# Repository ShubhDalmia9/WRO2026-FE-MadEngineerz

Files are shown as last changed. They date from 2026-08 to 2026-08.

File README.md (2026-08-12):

# 🏁 WRO 2026 Future Engineers — MadEngineerz

<div align="center">

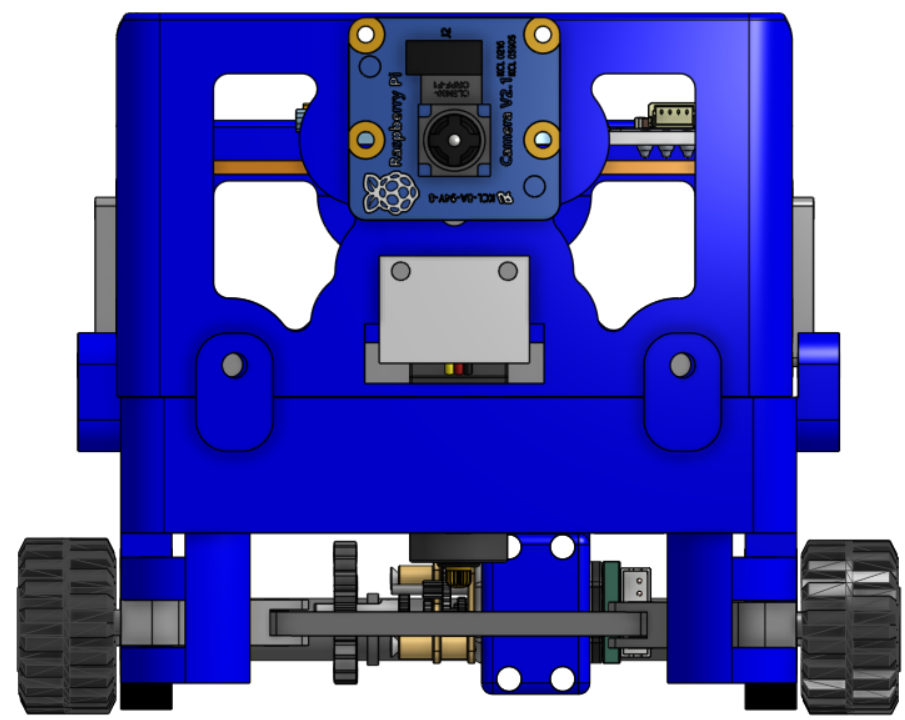
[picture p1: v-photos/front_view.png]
MadEngineerz autonomous vehicle


**Small. Efficient. Simple.**

</div>

---

Welcome to the repository of **Team MadEngineerz**, competing in the **World Robot Olympiad™ Future Engineers 2026** category.

We set out to build a compact autonomous vehicle in which every part earns its place. The design philosophy is stated in three words in our own ideology document, and it is not decoration: it decided the chassis dimensions, the drivetrain, the electronics construction method and the software architecture. Where a simpler answer was sufficient, we took it. Where minimalism would have cost capability, we did not.

The vehicle measures **121 mm (L) × 83 mm (W) × 83 mm (H)**. The printed mechanical structure, with no electronics fitted, weighs **72.92 g**. That figure is the sum of every printed part in the build and not an estimate; the breakdown is published part by part in the [Models documentation](models/README.md).

Every mechanical component was designed by the team in Onshape and manufactured in-house. Every electrical connection was made by the team on perfboard. Every line of software was written by the team. This repository contains all of it, along with the research documents behind each decision.

---

## 📚 Table of Contents

- [📂 Complete Documentation Structure](#complete-documentation-structure)
- [👥 The Team](#the-team)
- [🎯 Challenge Overview](#challenge-overview)
- [🤖 Our Robot](#our-robot)
- [🧭 Engineering Philosophy](#engineering-philosophy)
- [⚙️ Mechanical Systems](#mechanical-systems)
- [🔧 Electronic Systems](#electronic-systems)
- [💻 Software Architecture](#software-architecture)
- [🔬 Research & Development](#research--development)
- [🧪 Testing & Iteration](#testing--iteration)
- [🛠️ Engineering Challenges](#engineering-challenges)
- [🚗 Vehicle Photos](#vehicle-photos)
- [🌐 GitHub Utilization](#github-utilization)
- [♻️ Replication](#replication)

---

## 📂 Complete Documentation Structure 

<div align="center">

### Each folder carries its own detailed technical README

| 📁 Folder | 🎯 Technical Content | 📖 Documentation |
|---|---|---|
| **⚙️ Models** | **Mechanical engineering**<br>• Onshape CAD and 3MF manufacturing files<br>• Chassis, steering and drivetrain design<br>• Transmission and speed analysis<br>• Design iteration record | [🔗 Models Documentation](models/README.md) |
| **🔌 Schemes** | **Electrical engineering**<br>• Complete wiring schematic<br>• Power distribution and consumption analysis<br>• Component pinouts and reference schematics<br>• Full bill of materials and datasheets | [🔗 Schemes Documentation](schemes/README.md) |
| **💻 Source** | **Software**<br>• Raspberry Pi vision and navigation<br>• Arduino Nano actuator control<br>• Serial protocol and failsafe<br>• Eight research documents | [🔗 Software Documentation](src/README.md) |
| **📚 Other** | **Research and references**<br>• Design ideology<br>• Steering and propulsion research<br>• Battery placement study<br>• Component reference images | [🔗 Other Resources](other/README.md) |
| **👥 Team Photos** | Official and informal team photographs | [🔗 Team Photos](t-photos/README.md) |
| **🚗 Vehicle Photos** | Six orthographic views with component identification | [🔗 Vehicle Photos](v-photos/README.md) |

</div>

---

## 👥 The Team 

MadEngineerz is a student robotics team competing in WRO 2026 Future Engineers. Between two members the project covers mechanical design and CAD, electronics, software, strategy and research, which is why the documentation in this repository spans all of those disciplines rather than one.

<div align="center">

| Member | Grade | Role |
|---|:---:|---|
| **Shubh Dalmia** — *Team Leader* | 10 | Electronics, Mechanical Design, CAD, Strategy, Research |
| **Daksh Gupta** | 9 | Electronics, Strategy Integration, Software, Research |

**Coach:** Vipin Kumar

</div>

<div align="center">
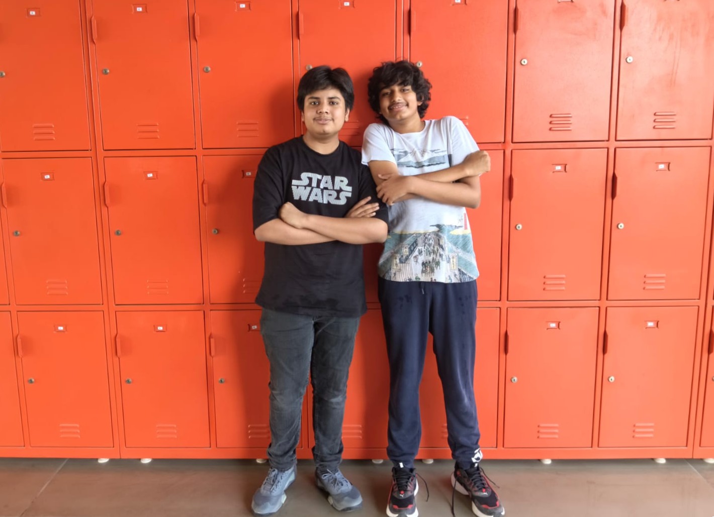
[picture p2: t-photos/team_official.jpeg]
MadEngineerz official team photo

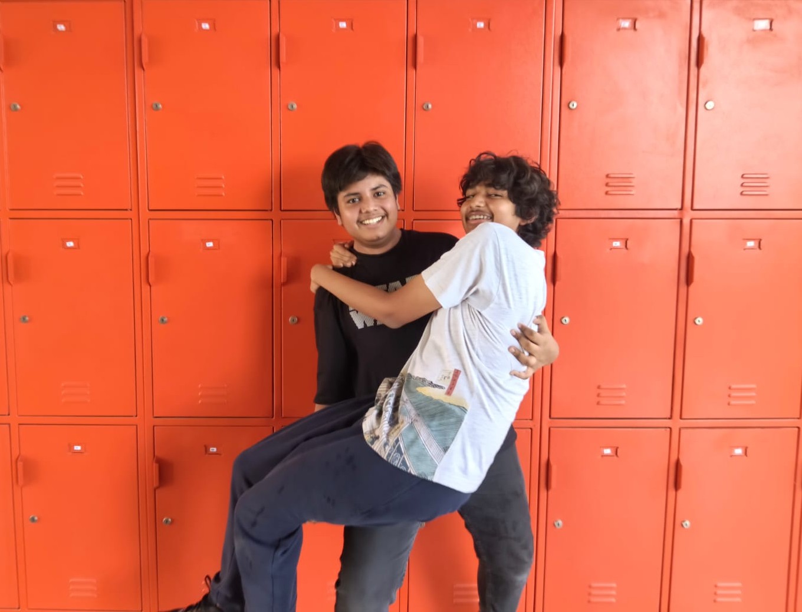
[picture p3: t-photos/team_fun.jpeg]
MadEngineerz informal team photo

</div>
<p align="center">
  <em>Official and informal team photographs. Full documentation in <a href="t-photos/README.md">t-photos</a>.</em>
</p>

---

## 🎯 Challenge Overview 

WRO Future Engineers sets two autonomous navigation problems on the same field. Our approach to each is summarised below and documented in full in the [Software Documentation](src/README.md).

### 🚀 Open Challenge

The vehicle navigates the track without obstacles, using the walls themselves as the reference.

```
Lane centering between the two walls, biased toward the inner wall
                              |
                              v
                Corner line detection (camera)
                              |
                              v
                    Corner line counting
                              |
                              v
                      11 lines counted
                              |
                              v
          Camera navigation yields to encoder odometry
                              |
                              v
        Drive a pre-calculated distance, then full stop
```

The control algorithm holds the vehicle centred between the inner and outer walls, with a deliberate bias toward the inner boundary to optimise cornering radii. Lap progress is tracked by counting corner marker lines through the camera. After the eleventh line the system changes state entirely: vision hands over to encoder odometry, which drives a known distance and stops.

### 🚧 Obstacle Challenge

The vehicle must pass red and green pillars on the correct side.

| Stage | Method |
|---|---|
| **Detection** | Raw YUV422 capture, U and V chrominance masking, red and green objects |
| **Centre calculation** | Mean X and Y of all masked pixels gives the pillar centroid |
| **Angle reference** | The camera is fixed on the chassis centreline, so the frame centre is 0° |
| **Relative angle** | Pixel offset between the pillar centroid and the frame centreline |
| **Avoidance** | Colour determines which side; angle determines how hard |
| **Steering** | PID control of the steering servo |

The target avoidance angle decreases approximately linearly as the pillar's pixel footprint grows, which indicates closing distance. The result is a smooth sweeping curve around a pillar rather than a late swerve.

### 📐 Where the mechanical engineering evidence sits

The mechanical evaluation looks at chassis design choices, the steering and drive mechanism, torque and speed reasoning, stability and rigidity, and the justification behind each decision. This table points to where each is evidenced rather than asserted.

| Evaluation area | Where it is documented |
|---|---|
| **Chassis design choices** | [Two-part chassis](#mechanical-systems) here, full reasoning and load-path analysis in [Models](models/README.md) |
| **Steering mechanism** | [Ackermann steering](#mechanical-systems), including why the short wheelbase makes the geometry matter more |
| **Drive mechanism** | [Rear-wheel drive and spur gear transmission](#mechanical-systems), including why the drive path is a straight shaft |
| **Torque and speed reasoning** | The 4:3 step-up derivation below, with the torque trade-off and why it suits this mass |
| **Stability and rigidity** | Closed-box architecture, 3 mm walls, eight-screw interface, sealed bearings; full table in [Models](models/README.md) |
| **Justification of design choices** | Every decision in this document is given with its reason; summarised in the [Models engineering summary](models/README.md) |
| **Testing used to refine the design** | [Testing & Iteration](#testing--iteration), with seven documented alternatives evaluated and rejected |

---

## 🤖 Our Robot 

<div align="center">
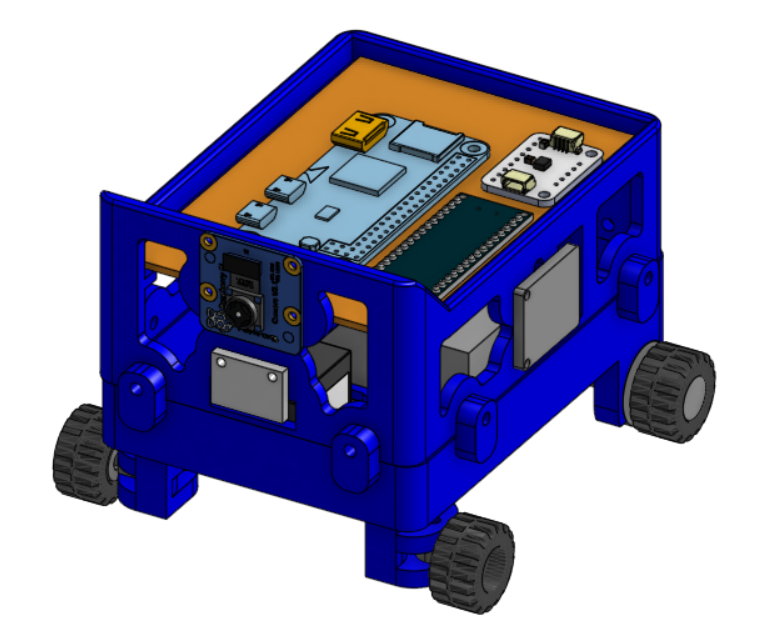
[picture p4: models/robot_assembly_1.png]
Complete CAD assembly

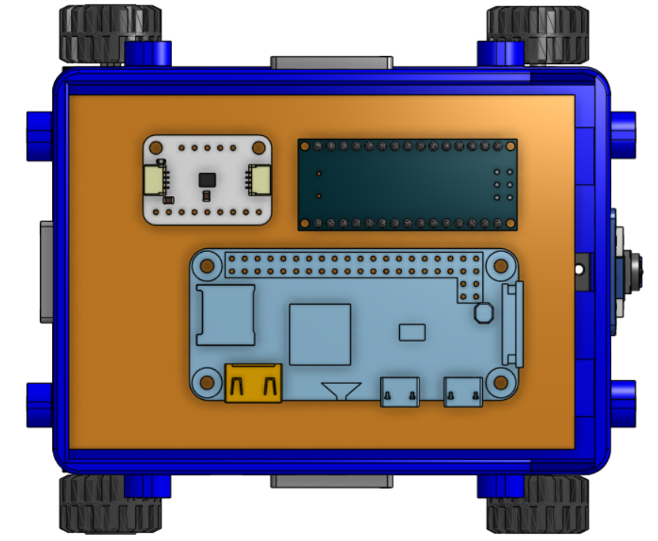
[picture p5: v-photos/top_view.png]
Electronics deck

</div>
<p align="center">
  <em>Left: complete CAD assembly. Right: the electronics deck on the upper chassis section, carrying the Raspberry Pi Zero 2 W, the Arduino Nano and the BNO085 IMU on a custom perfboard.</em>
</p>

### Mechanical architecture

| Feature | Implementation |
|---|---|
| Steering | Ackermann geometry on the front axle |
| Drive | Rear-wheel drive on a solid axle |
| Transmission | Spur gear pair, 20 T motor pinion to 15 T axle gear, a 4:3 step-up |
| Motor | N20 metal gear motor, 500 RPM output, with encoder |
| Chassis | Two-part construction, upper and lower sections joined by 8 M2 screws |
| Walls | 3 mm structural walls on both sections |
| Mounting | Components mounted directly to the printed structure, no intermediate brackets |
| Electronics access | Dedicated upper section forming a detachable electronics deck |
| Mass | 72.92 g printed structure, electronics excluded |
| Envelope | 121 × 83 × 83 mm |

### Electronic architecture

| Subsystem | Devices |
|---|---|
| Compute | Raspberry Pi Zero 2 W |
| Vision | Raspberry Pi Camera |
| Real-time control | Arduino Nano |
| Orientation | BNO085 IMU |
| Distance sensing | 1 × VL53L1X, 3 × VL53L3CX |
| Bus expansion | TCA9548A I²C multiplexer |
| Propulsion | TB6612FNG driver, 500 RPM N20 motor |
| Steering | EMAX ES08MA II servo |
| Power | MP1584 buck converter, 2S LiPo pack |

---

## 🧭 Engineering Philosophy 

Our ideology document reduces the whole project to three words: **small, efficient, simple**. Weight is treated as a resource to be spent, not a number to be minimised at any cost. The chassis is kept as small as practical to reduce material, mass and footprint. Components are reduced to the minimum required to reach the performance we need.

The most important consequence is stated explicitly in our own research: the robot is designed *as* a compact vehicle rather than as a scaled-down large one. A 72.92 g car does not behave like a small version of a heavy car, and the mechanical decisions follow from that rather than from convention.

| Domain | How the philosophy shows up |
|---|---|
| **Chassis** | 121 × 83 × 83 mm envelope fixed at concept stage, so every later packaging decision was a real constraint |
| **Weight** | Wall thickness refined from 4 mm to 3 mm, and the upper frame lightened, because the two chassis halves are 64.9 g of the 72.92 g total |
| **Mechanical** | Simple geometry and a minimal part count to reduce failure points |
| **Electronics** | Perfboard rather than a fabricated PCB, so the circuit can change as fast as the design does |
| **Software** | Lightweight Python, a NumPy channel mask instead of a vision framework, readable serial strings instead of binary packets |
| **Manufacturing** | Everything printed in-house, so a revision costs a print rather than a lead time |
| **Maintenance** | A detachable electronics deck and JST connectors so a module can be swapped without desoldering |

---

## ⚙️ Mechanical Systems 

Full detail, including the complete manufacturing file repository, is in the [Models Documentation](models/README.md).

### Core specifications

| Parameter | Value |
|---|---|
| Dimensions | 121 mm (L) × 83 mm (W) × 83 mm (H) |
| Wheelbase | 67 mm |
| Front track | 85 mm |
| Printed structure mass | 72.92 g |
| Structural wall thickness | 3 mm, both sections |
| Wheels | LEGO 87697, 21 mm diameter × 12 mm wide |
| Bearings | 626-2RS on the rear axle, 684-2RS at the front wheels |
| Fasteners | M2 throughout |

### 🔄 Ackermann steering

<div align="center">
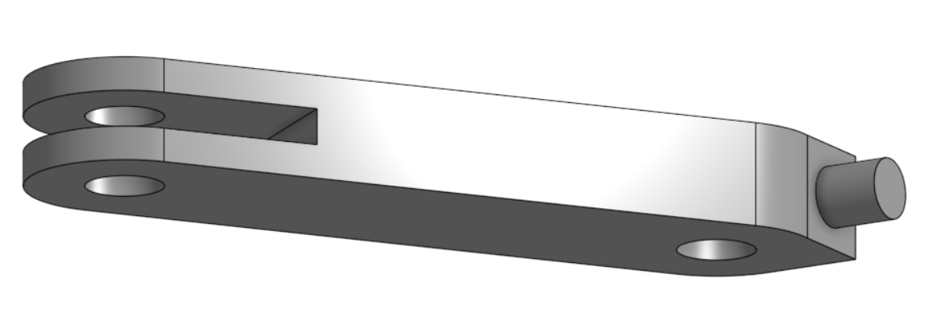
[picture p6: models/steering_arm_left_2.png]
Steering knuckle

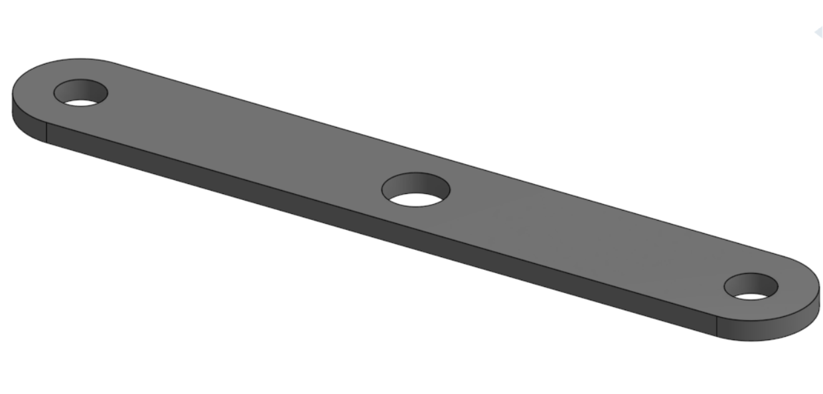
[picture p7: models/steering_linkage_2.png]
Steering linkage

</div>
<p align="center">
  <em>Mirrored steering knuckle with clevis, stub axle and M2 kingpin bore, and the linkage that drives both knuckles from a single servo input at its centre hole.</em>
</p>

In a turn the inner and outer front wheels travel on circles of different radii about the same centre. Steering both to the same angle forces at least one wheel to point away from its direction of travel, and the difference is absorbed as tyre scrub. Ackermann geometry steers the inner wheel through a larger angle than the outer, so a perpendicular from each front wheel meets a perpendicular from the rear axle at one common point and both wheels roll along their true paths.

**Why it matters more on this vehicle.** Our wheelbase (67 mm) is shorter than our track (85 mm), which is an unusual proportion and a direct consequence of packaging a 121 mm car. The shorter the wheelbase relative to the track, the further the inner and outer steer angles must diverge for correct geometry. A long vehicle can approximate Ackermann with a nearly parallel linkage and lose very little. Ours cannot, so the geometry was set from the outset rather than approximated.

The benefit is not only efficiency. Scrub varies with surface, load and speed, so removing it makes the relationship between commanded steering angle and actual path repeatable, which is what an autonomous vehicle depends on.

**Actuator:** EMAX ES08MA II metal gear micro servo, selected for compact size, low mass, adequate torque and precise positioning. The metal gear train is the decisive property: the linkage transmits impact loads back into the servo whenever a wheel meets an obstruction.

### 🔧 Rear-wheel drive and spur gear transmission

<div align="center">
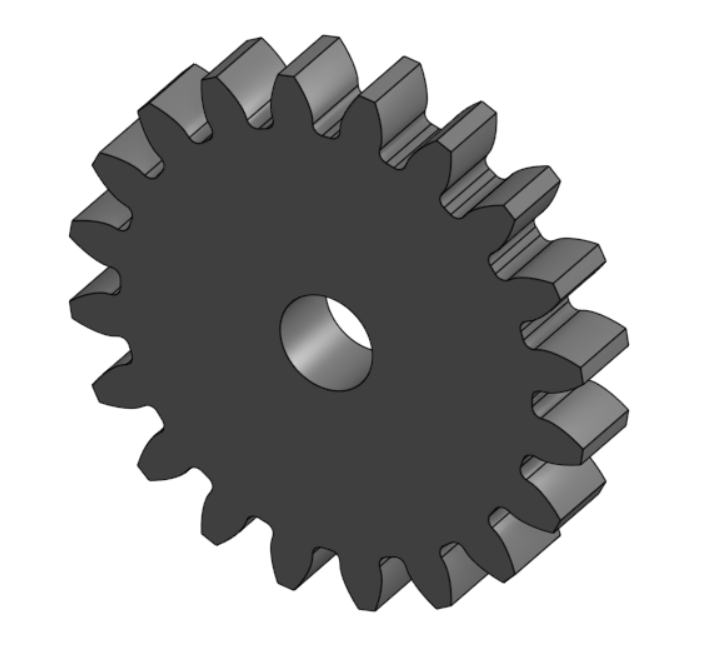
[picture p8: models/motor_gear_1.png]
20 tooth motor pinion

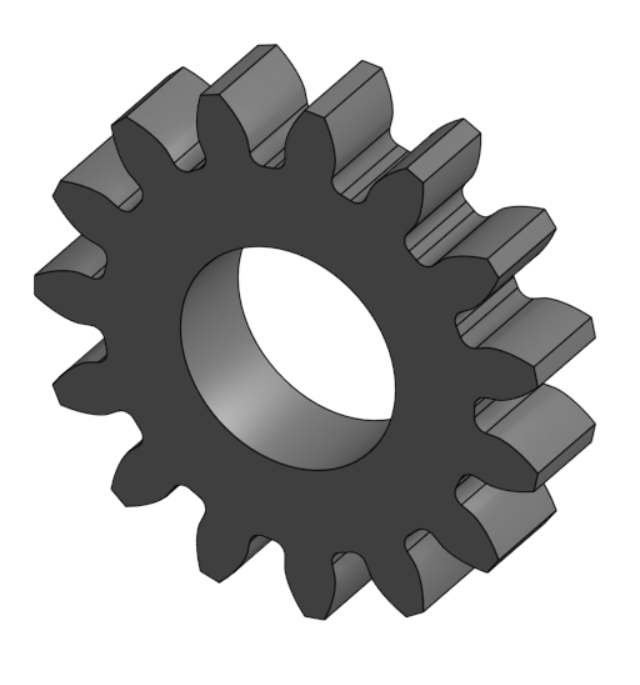
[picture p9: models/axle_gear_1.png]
15 tooth axle gear

Drive axle
</div>
<p align="center">
  <em>The 20 T motor pinion, the 15 T axle gear, and the drive axle whose cross-profile ends transmit torque to the rims by positive form lock rather than friction.</em>
</p>

**Why rear-wheel drive.** It separates steering from propulsion. A front-wheel-drive layout would require the drive path to accommodate a steering angle, which means flexible couplings or constant-velocity joints, both difficult to produce at this scale by FDM printing and both sources of play in the steering. Driving the rear axle keeps the drive path a single straight shaft and leaves the front axle a pure steering mechanism.

**Why spur gears.** A spur pair transmits torque between parallel shafts with no axial thrust component to react into printed plastic, and its entire tooth profile lies in one print layer plane, which is the geometry FDM reproduces most faithfully at this tooth size. Helical and double-helical forms were modelled and evaluated before the plain spur pair was adopted.

**Why this ratio.** The 20 T pinion drives the 15 T gear, so this is a step-up:

```
i        = 20 / 15 = 1.333        (4:3)
n_wheel  = 500 × 1.333 = 666.7 RPM
v        = π × 0.021 × (666.7 / 60) = 0.73 m/s     (theoretical, no load)
```

Torque moves the other way: whatever the ratio multiplies in speed, it divides in torque. On a vehicle of this mass, running on all four wheels in sealed ball bearings across a hard flat surface, the tractive force required is small. The useful margin is in lap time, not pulling force, so spending torque headroom to buy speed is the correct direction here and would be the wrong direction on a heavier vehicle. The step-up is also deliberately modest: a more aggressive ratio would raise reflected inertia with the square of the ratio and would diverge the gear diameters, which costs package volume in a 121 mm car.

### 🏗️ Two-part chassis

<div align="center">
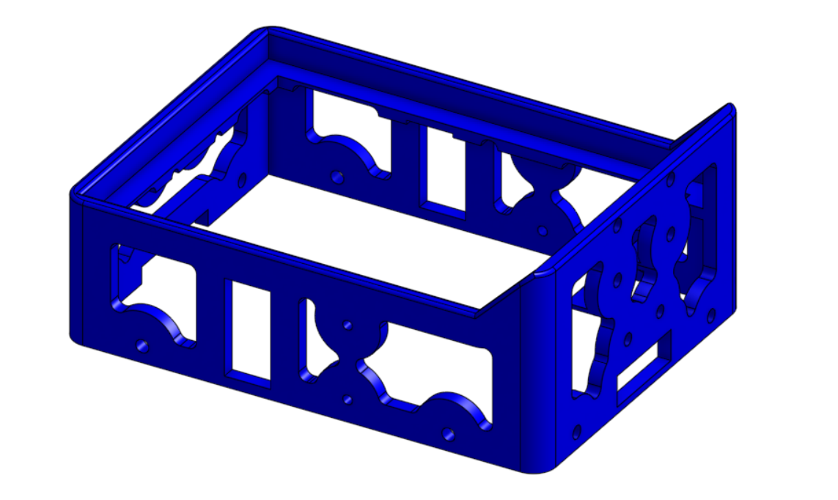
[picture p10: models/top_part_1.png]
Upper chassis section

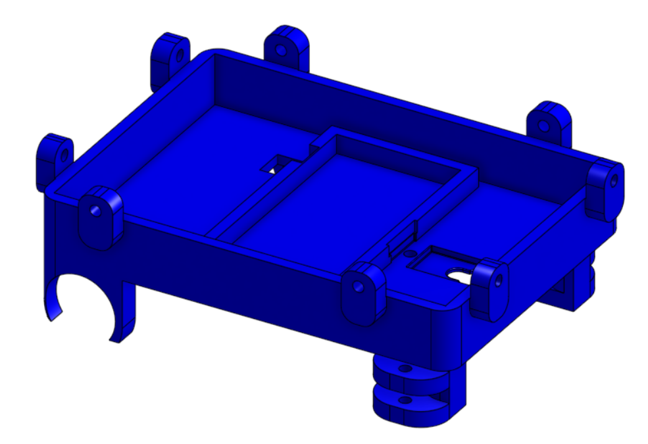
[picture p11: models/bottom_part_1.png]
Lower chassis section

</div>
<p align="center">
  <em>Upper section, an open lightened frame carrying the electronics deck, and lower section, a tray carrying the drivetrain and steering loads with paired kingpin lugs at each corner.</em>
</p>

The structure has to be stiff and it has to open. A single monolithic shell would either enclose the mechanism completely, making it unserviceable, or need large open faces that remove the very material providing stiffness. Splitting it lets each half be a closed-perimeter part in its own right, and the **8 M2 screws** across the interface recover the stiffness at the seam and hold the halves square. Joined, the two sections form a closed box, which is far stiffer in torsion than either half alone.

The load paths decided where material could be removed. The lower tray carries the drivetrain and steering loads and keeps its material. The upper frame carries only the electronics deck, so it was lightened using the **Lighten FeatureScript in Onshape**, which produced the aperture pattern visible above while leaving the closed perimeter rails that provide its torsional stiffness. The result is 26 g for the upper section against 38.9 g for the lower.

Components mount **directly to the printed structure** with no intermediate brackets. Every bracket would add mass, two more interfaces that can move, and tolerance stack. For the camera in particular, any compliance between the sensor and the wheels changes the relationship between what the robot sees and where it actually is.

### 🖨️ CAD and manufacturing

| Stage | Tool |
|---|---|
| CAD | Onshape |
| Manufacturing preparation | Part orientation and plate arrangement |
| Slicing | Bambu Studio |
| Printing | Bambu Lab A1 |
| Material | PLA |

```
Onshape → CAD Design → Manufacturing Preparation → Bambu Studio → 3D Printing → Assembly → Testing
```

PLA offers the highest stiffness of the common FDM materials along with excellent dimensional accuracy, which is the property this design actually depends on: the bearing seats, gear bores and screw interfaces all rely on printed dimensions landing within tolerance.

Manufacturing files are published in **3MF** rather than STL or vendor G-code. 3MF is an open format read by all major slicers, it retains the print configuration alongside the geometry, and it preserves the orientation and plate arrangement, which matters because orientation determines the direction of the layer lines relative to the loads and the printed bores. It does not guarantee identical output on every printer, since nozzle, extrusion system, calibration and filament all vary, but it preserves our configuration as the starting point.

We publish 3MF deliberately rather than native CAD source, so that another team can manufacture the robot exactly as designed while the design itself remains our own work.

### Manufacturing file repository

<div align="center">

| Component | File | Qty | Preview | Description |
|---|---|---:|---|---|
| **Bottom chassis** | [`Bottom part.3mf`](models/Bottom%20part.3mf) | 1 |  | Primary load-carrying tray, 3 mm walls, integrated steering lugs. 38.9 g |
| **Top chassis** | [`Top Part.3mf`](models/Top%20Part.3mf) | 1 |  | Lightened upper frame carrying the electronics deck. 26 g |
| **Drive axle** | [`Axle.3mf`](models/Axle.3mf) | 1 |  | Runs in two 626-2RS bearings, cross-profile ends. 2.30 g |
| **Axle gear (15 T)** | [`Axle gear.3mf`](models/Axle%20gear.3mf) | 1 |  | Driven gear of the transmission pair. 0.30 g |
| **Motor gear (20 T)** | [`Motor Gear.3mf`](models/Motor%20Gear.3mf) | 1 |  | Driving pinion on the N20 D shaft. 0.60 g |
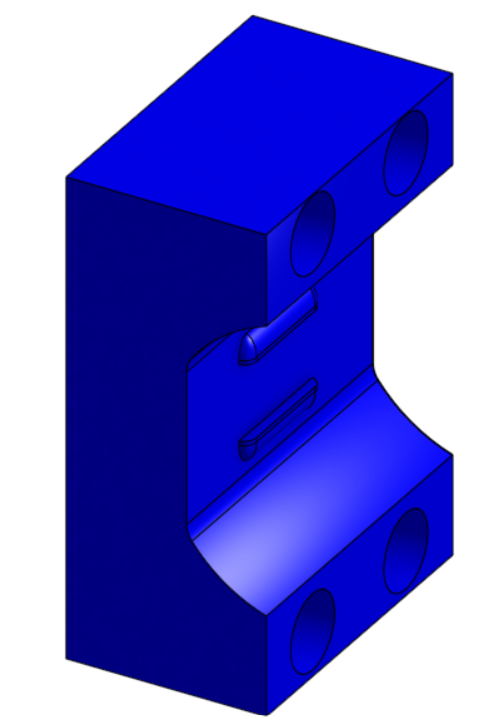
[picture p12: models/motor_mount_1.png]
| **Motor mount** | [`Motor mount.3mf`](models/Motor%20mount.3mf) | 1 |  | Fixes the N20 and sets the gear centre distance. 1.19 g |
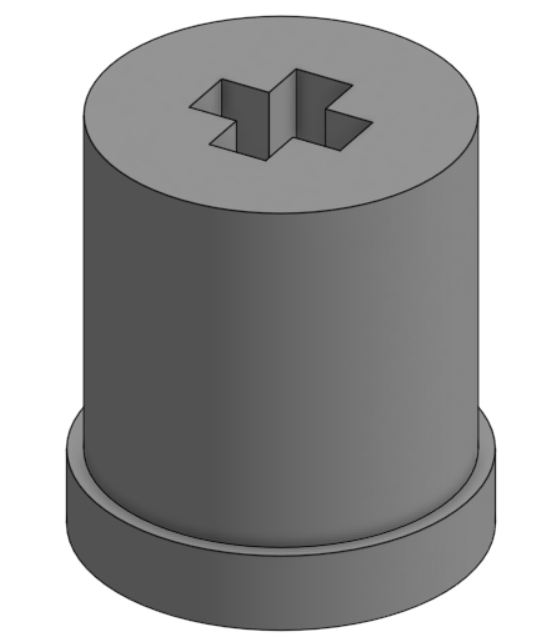
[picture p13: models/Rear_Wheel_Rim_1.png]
| **Rear wheel rim** | [`Rear wheel rim.3mf`](models/Rear%20wheel%20rim.3mf) | 2 |  | Adapter between axle end and LEGO 87697 wheel. 0.70 g each |
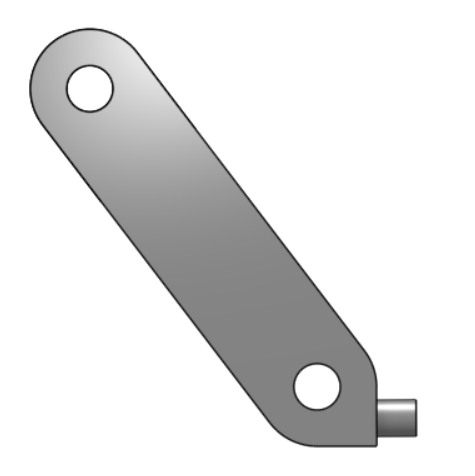
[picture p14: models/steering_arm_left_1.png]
| **Steering arm, left** | [`steering_arm_left.3mf`](models/steering_arm_left.3mf) | 1 |  | Left knuckle, clevis, stub axle, M2 kingpin bore. 0.80 g |
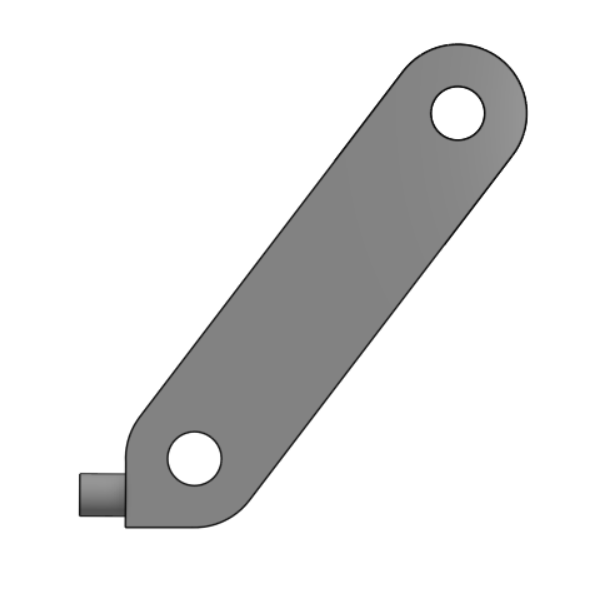
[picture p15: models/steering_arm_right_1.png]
| **Steering arm, right** | [`steering_arm_right.3mf`](models/steering_arm_right.3mf) | 1 |  | Mirrored right knuckle. 0.80 g |
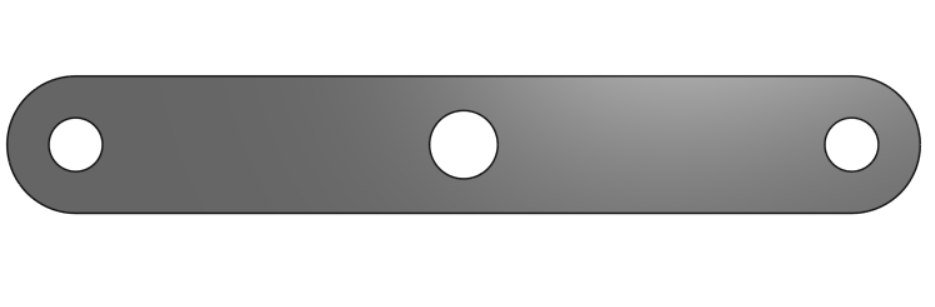
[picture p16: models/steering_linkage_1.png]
| **Steering linkage** | [`steering_linkage.3mf`](models/steering_linkage.3mf) | 1 |  | Outer holes to the knuckles, centre hole to the servo. 0.63 g |

</div>

### Mechanical engineering approach

**1. Conceptual design and requirements analysis.** Work started on paper, with a large number of sketches exploring vehicle layout, subsystem arrangement and component packaging before any CAD. Sketching is far faster than modelling for comparing alternatives, so unworkable layouts were set aside at the cost of a page. This stage produced the architecture: Ackermann steering, rear-wheel drive, and the fixed 121 × 83 × 83 mm envelope from which the wheelbase and track follow.

**2. Precision CAD modelling.** Every part was modelled parametrically in Onshape, with the interfaces that hold the design together defined as driven dimensions: gear centre distance, bearing seats, kingpin spacing, the screw pattern between the halves. Building the complete assembly rather than isolated parts is what allowed interference and packaging to be resolved in the model.

**3. Prototyping and optimisation.** The design iterations recorded below were carried out here, comparing alternatives directly against one another in the parametric assembly.

**4. Production engineering and validation.** Parts were prepared in Bambu Studio, printed in PLA on the Bambu Lab A1, and assembled with M2 fasteners and sealed bearings into the vehicle documented in this repository.

---

## 🔧 Electronic Systems 

Complete electrical documentation, including the wiring schematic, all pinouts and every datasheet, is in the [Schemes Documentation](schemes/README.md).

### Bill of materials

<div align="center">

| Component | Image | Qty | Function |
|---|---|---:|---|
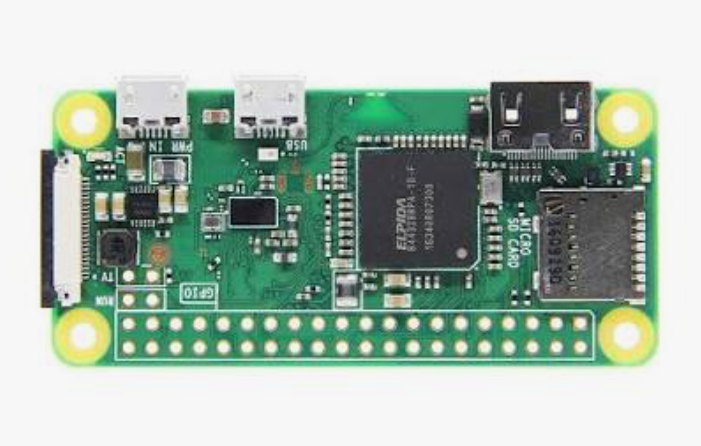
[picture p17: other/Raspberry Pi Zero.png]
| **Raspberry Pi Zero 2 W** |  | 1 | Main vision processor. Hosts the camera and the I²C bus, links to the Nano over UART |
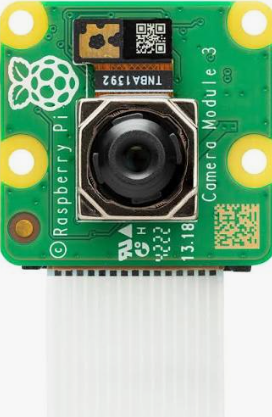
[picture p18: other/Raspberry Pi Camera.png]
| **Raspberry Pi Camera** |  | 1 | Primary visual sensor for track layout, pillar and corner line recognition |
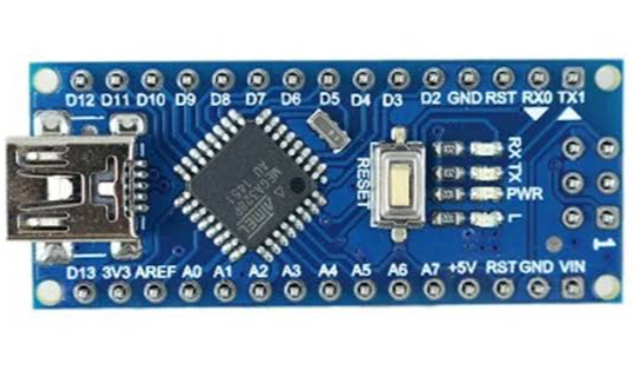
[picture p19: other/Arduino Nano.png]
| **Arduino Nano** |  | 1 | Low-level real-time controller for motor drive and encoder pulses |
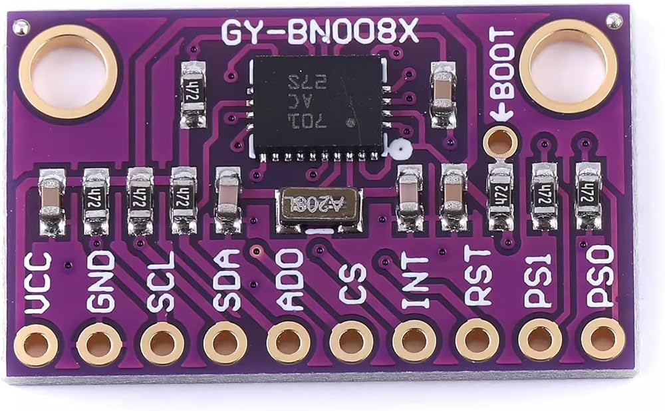
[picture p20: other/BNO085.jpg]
| **BNO085** |  | 1 | 9 DoF orientation IMU with on-board sensor fusion |
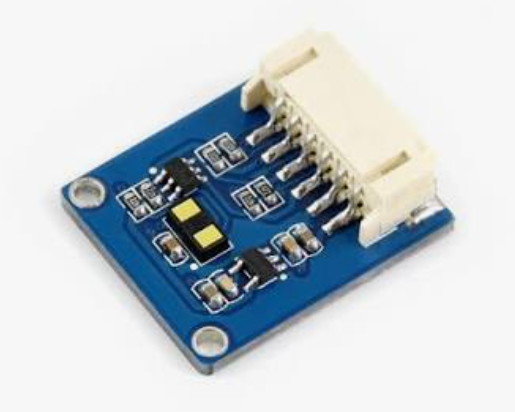
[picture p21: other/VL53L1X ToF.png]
| **VL53L1X** |  | 1 | Time-of-Flight ranging, up to 400 cm, 27° typical full field of view |
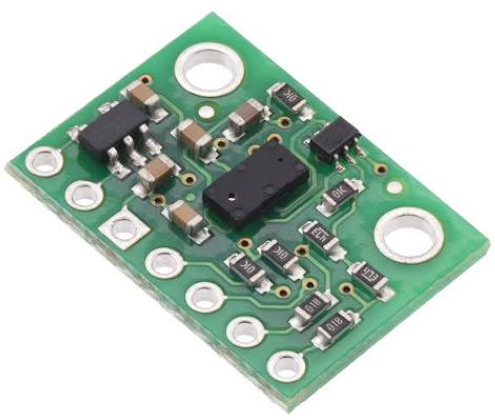
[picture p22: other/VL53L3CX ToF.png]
| **VL53L3CX** |  | 3 | Time-of-Flight ranging with multi-target detection, 25° typical full field of view |
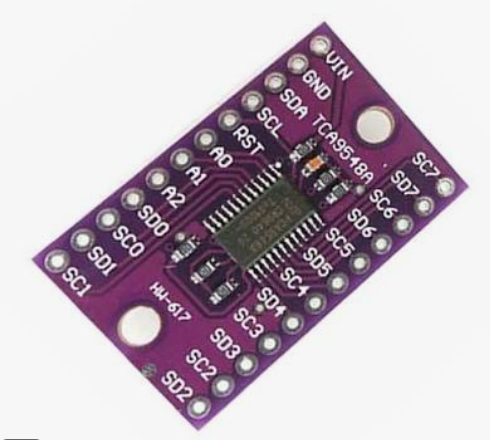
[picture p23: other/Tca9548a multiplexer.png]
| **TCA9548A** |  | 1 | 8 channel I²C multiplexer, one channel per ranging sensor |
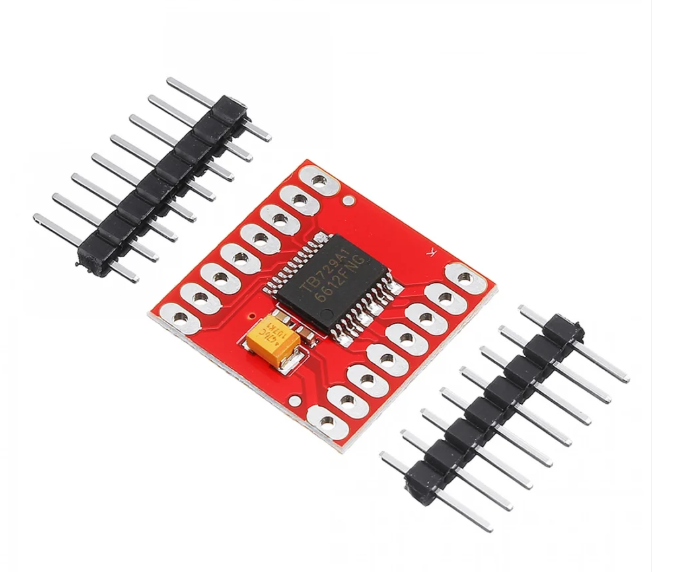
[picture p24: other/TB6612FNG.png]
| **TB6612FNG** |  | 1 | H-bridge motor driver for the drive motor |
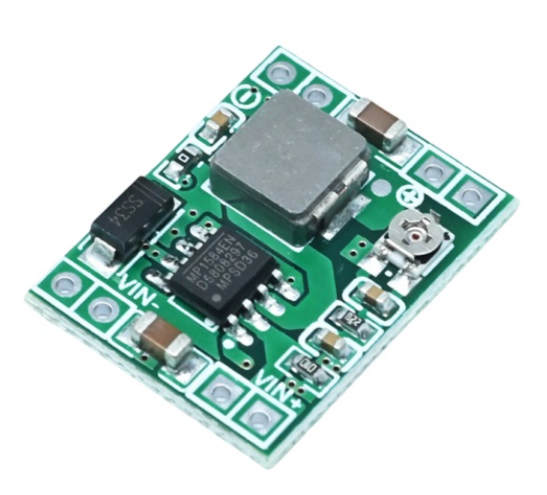
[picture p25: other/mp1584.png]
| **MP1584** |  | 1 | Step-down switching buck converter producing the regulated logic rail |
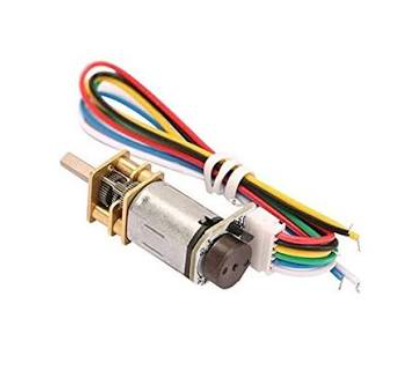
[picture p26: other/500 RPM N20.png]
| **500 RPM N20** |  | 1 | Metal gear DC motor with encoder, drives the rear axle |
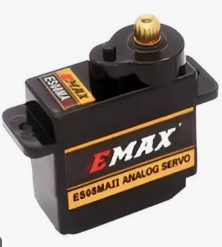
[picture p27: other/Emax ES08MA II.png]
| **EMAX ES08MA II** |  | 1 | Metal gear micro servo, steering actuator |

</div>

### ⚡ Electrical design philosophy

The electrical system was built so that the team could assemble, modify, troubleshoot and maintain every part of it ourselves. Several decisions follow directly from that.

**Switching regulation over linear.** Logic and sensing are supplied through a high-efficiency buck converter rather than a linear regulator such as an LM7805. A linear part dissipates the voltage difference as heat, and in a compact chassis that heat has nowhere to go while the wasted energy shortens usable run time.

**Noise isolation by topology.** The layout separates clean logic lines from high-noise inductive loads. The motor and the driver draw directly from the pack or from dedicated converter lines, so the PWM drive commands and the high-frequency encoder pulses stay clear of electromagnetic interference and ground bounce. That isolation is not incidental: the encoder is the vehicle's source of distance for dead reckoning, and a corrupted pulse train degrades position tracking directly.

**Modular cabling.** All sensors, power rails and actuators use polarised JST connectors, so a component can be swapped instantly during troubleshooting in pit conditions without re-soldering.

**Accessible compute.** The compute boards, the multiplexer and the IMU sit at the top of the vehicle in a detachable assembly, giving direct access for debugging, wiring, last-minute changes and flashing code.

### 🔨 Custom perfboard-based electronics

Our electronics are built on **custom perfboard** rather than a professionally manufactured PCB. This is a deliberate choice suited to how the robot was developed, not a claim that perfboard is better in general. A fabricated PCB gives a more finalised and more compact result, and for a settled design it is the better answer. The difference is what happens when the design changes: a PCB change generally requires another board revision and another manufacturing cycle, whereas the perfboard circuit can be modified directly, in place.

<div align="center">

| Aspect | Professional PCB | Our perfboard system |
|---|---|---|
| Development | Fixed after manufacturing | Easily modified |
| Modification | Requires a board revision | Direct modification |
| Development cost | Higher for repeated revisions | Low |
| Hands-on experience | Lower | High |
| Component replacement | More difficult | Easier |
| Manufacturing | External fabrication | In-house |
| Flexibility | Lower after fabrication | High |

</div>

Three devices are mounted on the perfboard itself: the **Raspberry Pi Zero 2 W**, the **Arduino Nano** and the **BNO085 IMU**. Everything else connects up from below, from wherever it sits in the chassis. The processors and the IMU have no reason to be anywhere but the deck, while the camera, the ranging sensors, the driver, the motor and the servo must sit where their function places them. Making the perfboard the single upper interconnection point means each distributed device needs one run up to a common landing rather than a web of connections between themselves.

### 🔌 Wiring, power and cable management

**Wiring.** The complete digital wiring schematic is published as [`WIRING.pdf`](schemes/WIRING.pdf) and is the source of truth for every electrical connection: the battery, the MP1584 input and output, the Raspberry Pi GPIO header, the Arduino Nano and its USB bus, the TB6612FNG and the N20 motor, the servo, the TCA9548A and its downstream ranging sensors, and the common ground.

**Power distribution.** A 2S LiPo pack supplies the vehicle. The motor driver is the only device that takes the raw pack voltage; everything else sits behind the buck converter and is insulated from the voltage sag the motor causes when it loads. Because most of the sensing hardware tolerates either 3.3 V or 5 V, the rail count stays low rather than requiring separate regulation per sensor family. Common ground is the negative terminal of the pack, giving every device one fixed voltage reference. Rail assignments and the full consumption analysis are in [`Power System..pdf`](schemes/Power%20System..pdf) and summarised in the [Schemes Documentation](schemes/README.md).

**Cable management.** The vehicle has a relatively large open central region between the upper and lower chassis sections, and the cabling is built around that space rather than around routing hardware. Wiring from the upper portion and from the lower portion both meet there, so the cabling is a set of short runs into one area instead of long runs across the vehicle. Connections converge at one identifiable region, so a wire can be traced from either end. The two halves can be wired and checked separately and then joined. Separating the sections exposes the whole cable run at once for maintenance. And routing through the centre keeps cabling clear of the steering linkage and the rear axle and gear pair, the only moving parts that could catch a wire.

---

## 💻 Software Architecture 

Full implementation detail, including code excerpts and an explicit implementation status table, is in the [Software Documentation](src/README.md).

```
+---------------------------------------------------------------+
|                        RASPBERRY PI                           |
|                          (Python 3)                           |
|                                                               |
|   Camera  ->  Vision pipeline      Time-of-Flight array       |
|   Rotary encoder odometry          High level navigation      |
|                    Steering PID calculation                   |
+-------------------------------+-------------------------------+
                                |
                                |  Serial, ASCII string messages
                                |  115200 baud
                                v
+---------------------------------------------------------------+
|                        ARDUINO NANO                           |
|                       (Embedded C++)                          |
|   Servo steering angle execution                              |
|   DC motor direction and PWM speed control                    |
+-------------------------------+-------------------------------+
                                |
                       +--------+--------+
                       |                 |
                       v                 v
                 Steering servo     Drive motor
```

**Why the split.** The Pi is the only platform on the robot capable of running a camera pipeline, and it is a poor platform for deterministic timing because it runs a general-purpose operating system. The Nano is the reverse. Giving each task the platform suited to it means the vision loop can take as long as it needs without stalling the motor, while the servo pulse train and the PWM stay deterministic regardless of what the Pi is doing.

The split also creates a clean failure boundary. The Nano holds the last commanded values and runs its own watchdog, so a stall on the Pi stops the motor rather than leaving it running at the last commanded speed.

### Development and deployment

| Platform | Language | Deployment |
|---|---|---|
| Raspberry Pi | Python 3 | SSH over direct Ethernet or a dedicated hotspot |
| Arduino Nano | C++ | Arduino IDE over a direct USB serial link |

Competition rules restrict external discrete LEDs, so system boot and script execution are indicated using the Raspberry Pi's onboard green ACT LED mapped through GPIO triggers. It confirms that the system has started, and nothing more.

### Serial communication

The link uses **human-readable ASCII strings rather than binary packets**, because strings are easier to read on a terminal, easier to debug when a value looks wrong and easier to modify when a field changes. The cost is a small reduction in efficiency, accepted deliberately.

```
$<servoAngle>,<motorSpeed>\n
```

`$` marks the start of a valid payload, the comma separates the fields and the newline terminates it. The Nano parses the string, replies `OK`, and runs a **200 ms watchdog**: if no valid packet arrives within that window the drive throttle is forced to zero and the built-in LED lights as a warning. Because the timer only refreshes on a successful parse, a corrupted stream triggers the failsafe just as a disconnected cable would. This is what makes the Pi's non-deterministic timing safe to build on.

### Vision

```
Raw camera feed → YUV422 capture → discard Y channel
      → threshold masks on U and V → NumPy vectorised pixel mean → relative angle
```

Obstacle processing runs in ten steps:

1. Capture raw YUV422
2. Take the U and V chrominance channels
3. Discard Y for the colour detection step
4. Apply the colour mask
5. Detect red and green regions
6. Calculate the mean X and Y coordinates of the matching pixels
7. Take that mean as the obstacle centre
8. Measure the relative angle from the frame centreline
9. Determine the avoidance direction from colour and angle
10. Apply the correction through PID steering

The pipeline is specified as QQVGA at approximately 70 FPS in raw YUV422. Converting every frame to BGR or HSV would cost processing time the Pi Zero 2 W does not have, so raw YUV422 is captured directly and the luminance channel is discarded, leaving the two chrominance channels from which a colour mask is built by indexing rather than transforming. The centroid is the arithmetic mean of the matching pixel coordinates, which returns a position in milliseconds without contour fitting or blob analysis. The camera provides block detection, corner line detection, turning decisions and obstacle detection.

### Sensor roles

| Sensor | Primary role | Priority behaviour |
|---|---|---|
| **Camera** | Primary navigation | Relative target angles for cornering, pillar detection and track colour lines. Holds primary control during open track driving |
| **Rotary encoder** | Odometry and distance | Physical movement tracking for parking manoeuvres and final lap completion |
| **Time-of-Flight** | Spatial safety net | Continuously monitors close proximity and acts as a fail-safe override, forcing corrective steering near a wall and overriding camera input |

The hierarchy is contextual rather than a fixed blend. The camera leads on open track, the encoder leads where position matters more than vision, and the ToF array can pre-empt both when a collision is imminent. That inversion is the point of the ToF sensors: a wall at close range is a situation where the camera's judgement is not allowed to win.

### Implementation status

The camera pipeline, both sides of the serial protocol and the watchdog failsafe are implemented and running. The PID steering loop, the reference angle module, corner line detection and counting, lane centering, odometry, ToF handling and sensor fusion arbitration are designed and documented but not yet written. Two of the five source files are test routines rather than control software. The [Software Documentation](src/README.md) states the status of every capability item by item rather than leaving it to be inferred.

---

## 🔬 Research & Development 

Design decisions in this project were researched before they were built. The research documents are published in full alongside the code and models.

| Research | Document | What it decided |
|---|---|---|
| **Design ideology** | [`Ideology..pdf`](other/Ideology..pdf) | The small, efficient, simplistic principle and how it applies across mechanical, electrical and software design |
| **Steering and propulsion** | [`Hardware..pdf`](other/Hardware..pdf) | Ackermann selection and servo choice, plus a comparison of three transmission options: spur gear drive, timing belt drive and rear differential drive |
| **Battery placement** | [`Battery plan.pdf`](other/Battery%20plan.pdf) | Where the battery sits and how rear axle loading affects Ackermann steering authority |
| **Code architecture** | [`Code Architecture..pdf`](other/Code%20Architecture..pdf) | Sensor reliance, software structure and the parking approach |
| **Electrical philosophy** | [`Electrical_design_Philosophy.pdf`](schemes/Electrical_design_Philosophy.pdf) | Power architecture, noise isolation, sensor fusion strategy, communication and serviceability |
| **Power system** | [`Power System..pdf`](schemes/Power%20System..pdf) | Rail assignments, distribution architecture and consumption analysis |
| **Software research** | [Eight documents in `src/`](src/README.md) | Core components, vision pipeline, navigation strategies, sensor fusion, build process, dependencies, challenges, known issues |

One example of research changing the design: the battery study established that mass carried on the solid rear axle reduces the load on the Ackermann-steered front axle, and therefore reduces steering authority. That relationship constrains battery position at both ends, and it is why the pack sits above the drivetrain rather than at the rear.

Complete resource index in [Other Resources](other/README.md).

---

## 🧪 Testing & Iteration 

### Mechanical design iteration

The mechanical design reached its current form through two phases: sketching on paper, then evaluation in the parametric CAD assembly. Each alternative below was modelled and compared before one was adopted.

<div align="center">

| # | Subsystem | Alternatives evaluated | Outcome |
|---|---|---|---|
| 1 | Transmission ratio | Multiple tooth count combinations modelled | 20 T motor and 15 T axle (4:3) adopted |
| 2 | Gear type | Helical and double-helical gears modelled | Plain spur gear pair adopted |
| 3 | Wall thickness | 4 mm walls | Refined to 3 mm |
| 4 | Chassis architecture | Single-piece chassis | Split into two sections |
| 5 | Rear drive | Mechanical differential considered | Spur gear drive on a solid axle adopted |
| 6 | Upper section mass | Solid upper frame | Lightened with the Onshape Lighten FeatureScript |
| 7 | Component layout | Multiple component positions | Fixed once weight distribution and packaging were satisfactory |

</div>

Because both gears are small printed parts, evaluating a ratio was inexpensive, which is what made comparing several combinations practical rather than picking one at the outset. The same is true of the wall thickness change: the chassis sections are 64.9 g of the 72.92 g total, so wall thickness is the single largest lever on vehicle mass, and a 25% reduction acts on the two largest parts in the vehicle.

The differential decision is recorded with its consequence accepted rather than hidden. A solid axle constrains both rear wheels to the same speed, so some rear scrub occurs in a turn. At this mass the resulting forces are small, while a printed differential would have added several gears, bearing surfaces and a housing to the one subsystem that transmits continuous load. Reduced scrub is delivered at the front axle by the Ackermann geometry, where the steering angles make it matter most.

### Hardware validation

The manufacturing files published here were printed and assembled into the complete vehicle. That confirms the dimensional interfaces designed in CAD transfer correctly to printed parts and function together: the bearing seats, the gear centre distance set by the motor mount, the cross profile between axle and rim, the kingpin lugs and the eight-screw chassis interface.

### Software refinement

Both documented software challenges below were resolved through iteration rather than first-attempt design, and one of them changed the detection algorithm that the vehicle still uses.

Quantitative mechanical testing, meaning measured steering angles, turning radius, vehicle speed under load and structural deflection, is the next stage of work. No numerical values for those are claimed anywhere in this repository.

---

## 🛠️ Engineering Challenges 

### SSH access to the Raspberry Pi

**Challenge.** SSH over Wi-Fi through VS Code could not be made to work despite extended effort. Without SSH there was no way to test the code at all, because most of the libraries it depends on only run on the Raspberry Pi itself.

**Approach.** Multiple solutions were attempted over hours before the approach was changed rather than continued.

**Solution.** Wi-Fi was dropped entirely in favour of Ethernet. It was later found that a hotspot configured to WPA2 on an older phone was the only way to get the Pi Zero to connect to a network at all.

**Current status.** Deployment runs over SSH via direct Ethernet, with the WPA2 hotspot available for network connectivity. SSH itself still requires the direct Ethernet connection to a laptop.

### Obstacle detection performance

**Challenge.** The obstacle detection algorithm worked, but it was slow, reported a low frame rate, struggled under varying lighting, and overloaded the CPU of a test Raspberry Pi 3, which is considerably more powerful than the Zero the robot actually carries. It also drew bounding boxes above the obstacles rather than on them.

**Approach.** The problem was traced to how the detection defined an obstacle's position.

**Solution.** The algorithm was changed to work from the centre of an obstacle rather than from its corner.

**Current status.** The pipeline is centroid based, computing the mean X and Y of the masked pixels. This is what runs today and what will feed the PID avoidance algorithm.

### Packaging within a 121 mm envelope

**Challenge.** Fixing the envelope at concept stage meant every subsystem had to fit a space decided before any of them were designed.

**Approach.** The complete assembly was modelled in Onshape rather than individual parts, so interference and packaging could be resolved in the model, and component positions were moved repeatedly until both weight distribution and layout were satisfactory.

**Solution.** Mounting features are dimensioned to the components they hold, so each component's own body becomes part of the assembly's dimensional chain rather than sitting on a bracket.

**Current status.** The final layout is the one documented in the [Vehicle Photos](v-photos/README.md), with a wheelbase of 67 mm and a track of 85 mm following from the envelope.

---

## 🚗 Vehicle Photos 

Six orthographic views document the vehicle from every principal direction, each annotated with the components it makes visible.

<div align="center">
Front view
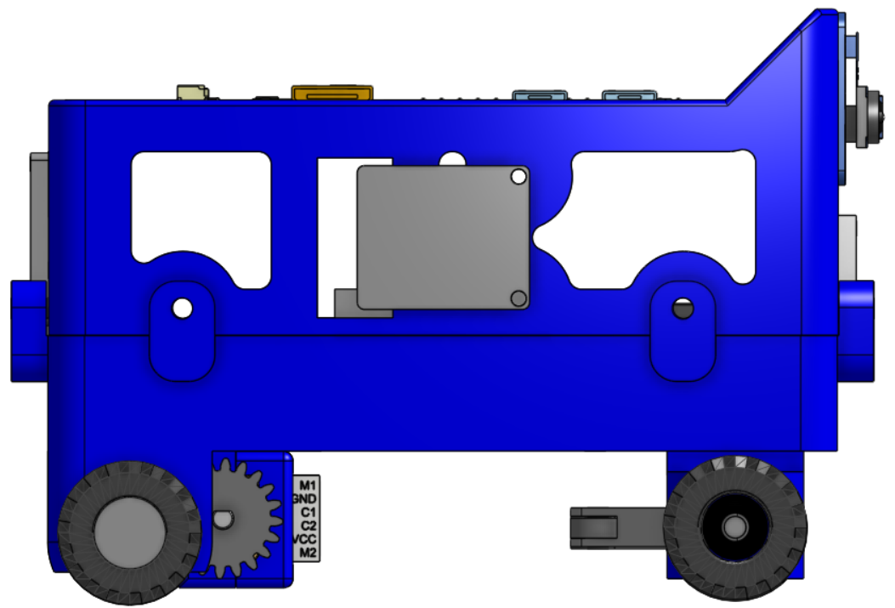
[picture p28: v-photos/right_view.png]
Right view

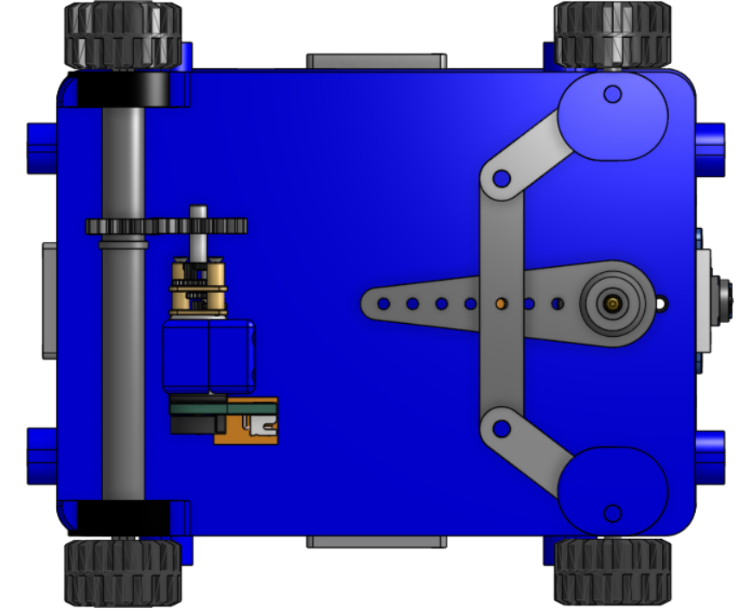
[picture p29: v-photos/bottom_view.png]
Bottom view

</div>
<p align="center">
  <em>Front view showing the camera and front steering assembly; right view showing the motor installation and the chassis interface; bottom view showing the drivetrain, the spur gear pair and the Ackermann steering mechanism.</em>
</p>

Complete set with per-view component identification in [Vehicle Photos](v-photos/README.md).

---

## 🌐 GitHub Utilization 

This repository is organised so that the project can be understood, inspected, manufactured and modified by someone who was not involved in building it.

<div align="center">

| Asset type | Location | Role |
|---|---|---|
| Manufacturing files | [`models/`](models/README.md) | 3MF files for every printed part, with quantities, masses and previews |
| Mechanical documentation | [`models/README.md`](models/README.md) | Design reasoning, transmission analysis, iteration record |
| Electrical schematics | [`schemes/`](schemes/README.md) | Complete wiring schematic and per-component reference schematics |
| Datasheets and pinouts | [`schemes/`](schemes/README.md) | Manufacturer datasheets for every electronic component |
| Source code | [`src/`](src/README.md) | Python and C++ sources with documented implementation status |
| Research | [`other/`](other/README.md) and [`src/`](src/README.md) | The design studies behind each major decision |
| Photographs | [`v-photos/`](v-photos/README.md), [`t-photos/`](t-photos/README.md) | Vehicle views and team documentation |

</div>

Each folder carries its own README rather than deferring everything to this page, so a judge or a reader can go directly to the discipline they care about. This root document explains the engineering decisions and points to the depth; it does not duplicate it.

Two conventions are worth noting. Research documents are published as they were written, including the ones that were later superseded by a design change, so the reasoning is visible and not only the conclusion. And the software documentation states which capabilities are implemented and which are designed but not yet written, rather than describing planned work as finished.

---

## ♻️ Replication 

The repository is intended to let another team understand and reproduce this project.

| To reproduce | Use |
|---|---|
| The mechanical structure | 3MF manufacturing files with orientation and print configuration preserved, plus per-part quantities and masses |
| The electronics | Complete wiring schematic, bill of materials, pinouts and manufacturer datasheets |
| The power system | Rail assignments, distribution architecture and consumption analysis |
| The software | Full Python and C++ sources, the serial protocol specification and eight research documents |
| The assembly | Fastener specification, bearing designations, and six orthographic views showing component placement |
| The reasoning | Research documents and the iteration record, so decisions can be evaluated rather than only copied |

Some honesty about the limits. The software is partially implemented, and the documentation says which parts. Quantitative mechanical test data does not yet exist. A team reproducing this robot would be reproducing a design that is complete mechanically and electrically, and in progress in software.

We publish 3MF rather than native CAD source deliberately: another team can manufacture the robot exactly as we designed it, while the design itself remains our own work.

---

---

<div align="center">

## 📚 Documentation Hub

| | |
|---|---|
| ⚙️ **Mechanical design and manufacturing** | [Models Documentation](models/README.md) |
| 🔌 **Electrical schematics and power** | [Schemes Documentation](schemes/README.md) |
| 💻 **Software implementation** | [Software Documentation](src/README.md) |
| 📚 **Research and component references** | [Other Resources](other/README.md) |
| 👥 **Team** | [Team Photos](t-photos/README.md) |
| 🚗 **Vehicle** | [Vehicle Photos](v-photos/README.md) |

### Team MadEngineerz — WRO 2026 Future Engineers

**Small. Efficient. Simple.**

</div>

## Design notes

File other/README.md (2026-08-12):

# Other Resources

Supplementary material for Team MadEngineerz, WRO 2026 Future Engineers. This folder holds component references and the research documents that informed the robot's design.

## Electronic Components

| Component | Image | Description |
|---|---|---|
| **Raspberry Pi Zero W** |  | Main compute board. Runs the vision pipeline and navigation. |
| **Raspberry Pi Camera** |  | Primary navigation sensor. Used for obstacle detection and colour identification. |
| **VL53L1X ToF** |  | Time of flight distance sensor. |
| **VL53L3CX ToF** |  | Time of flight distance sensor. |
| **Arduino Nano** |  | Secondary microcontroller. |
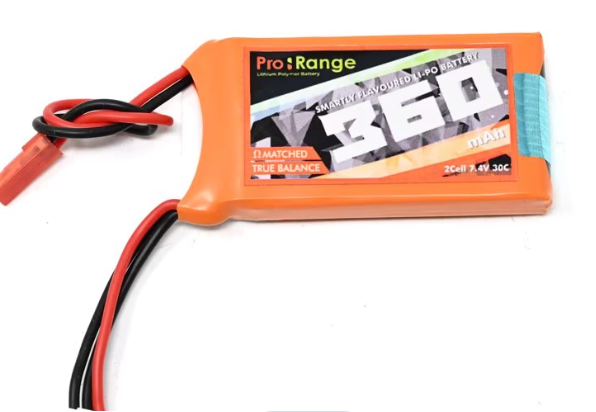
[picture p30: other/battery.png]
| **360 mAh 7.4 V 2S 30C LiPo** |  | Main battery pack. |
| **MP1584** |  | Step down voltage regulator module. |
| **EMAX ES08MA II** |  | Metal gear micro servo. Actuates the Ackermann steering linkage. |
| **500 RPM N20** |  | 6 V metal gear motor with encoder. Drives the rear axle. |
| **BNO085 IMU** |  | Inertial measurement unit. Supports parking guidance and path mapping. |
| **TCA9548A** |  | I2C multiplexer for running multiple I2C devices on one bus. |
| **TB6612FNG** |  | Motor driver. |

## Research & Design

| Resource | Document | Description |
|---|---|---|
| **Design ideology** | [`Ideology..pdf`](./Ideology..pdf) | The three principles the robot is built on: small, efficient, simplistic. Sets the target total mass of roughly 100 to 200 g, minimal battery capacity, a compact chassis, lightweight maintainable software and simplified CAD. |
| **Steering research** | [`Hardware..pdf`](./Hardware..pdf) | Ackermann steering selection, the reasoning behind reduced tyre scrub and more consistent path tracking, and the choice of the EMAX ES08MA II as the steering actuator. |
| **Propulsion research** | [`Hardware..pdf`](./Hardware..pdf) | Rear wheel drive layout with a single N20 motor, and the evaluation of three transmission options: spur gear drive, timing belt drive and rear differential drive, with the advantages and disadvantages of each. |
| **Battery placement and weight distribution** | [`Battery plan.pdf`](./Battery%20plan.pdf) | Battery specification and its position above the drivetrain, and the relationship between rear axle loading and the authority of the Ackermann steering system. |
| **Code architecture research** | [`Code Architecture..pdf`](./Code%20Architecture..pdf) | Optimized camera-based obstacle detection using YUV422 and NumPy, colour-based obstacle identification, relative angle calculation, PID-based steering, preliminary parking manoeuvre, and the simpler Open Challenge navigation strategy. |

## Technical Documentation

| Area | Documentation |
|---|---|
| Mechanical design and manufacturing files | [Models](../models/README.md) |
| Electrical design and schematics | [Schemes](../schemes/README.md) |
| Software implementation | [Source](../src/README.md) |

*Team MadEngineerz, WRO 2026 Future Engineers*

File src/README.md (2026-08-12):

# Software Documentation

Software for the MadEngineerz WRO 2026 Future Engineers robot. The system is split across two computing platforms: a Raspberry Pi running Python for perception and decision making, and an Arduino Nano running C++ for actuator control. This folder contains the source files and the research documents behind them.

This page documents both. Where the research describes something the code does not yet implement, it is labelled as planned rather than presented as working.

## Contents

* Software Architecture
* Programming Environment and Tools
* Development and Deployment
* Core Software Components
* Raspberry Pi and Arduino Communication
* Computer Vision System
* YUV422 Colour Detection
* Open Challenge Strategy
* Obstacle Challenge Strategy
* PID Steering Control
* Odometry
* ToF-Based Safety and Positioning
* Sensor Fusion
* Motor Control
* Steering Servo Control
* Software Development Philosophy
* Engineering Challenges and Solutions
* Implementation Status
* Known Issues, Gaps and TODOs
* Software Dependencies
* File Structure
* Technical Documentation

## Software Architecture

Two processors, with a hard split in responsibility.

```
+---------------------------------------------------------------+
|                        RASPBERRY PI                           |
|                          (Python 3)                           |
|                                                               |
|   Camera  ->  Vision      Time-of-Flight array                |
|               pipeline                                        |
|                                                               |
|   Rotary encoder odometry     High level navigation           |
|                               and state management            |
|                                                               |
|                    Steering PID calculation                   |
+-------------------------------+-------------------------------+
                                |
                                |  Serial, ASCII string messages
                                |  115200 baud
                                v
+---------------------------------------------------------------+
|                        ARDUINO NANO                           |
|                       (Embedded C++)                          |
|                                                               |
|   Servo steering angle execution                              |
|   DC motor direction and PWM speed control                    |
+-------------------------------+-------------------------------+
                                |
                       +--------+--------+
                       |                 |
                       v                 v
                 Steering servo     Drive motor
```

**Why the split.** The Pi is the only platform on the robot capable of running a camera pipeline, and it is a poor platform for deterministic timing because it runs a general purpose operating system. The Nano is the reverse. Putting perception and decision making on the Pi and actuator execution on the Nano gives each task the platform suited to it: the vision loop can take as long as it needs without stalling the motor, and the servo pulse train and PWM stay deterministic regardless of what the Pi is doing.

The split also gives a clean failure boundary. Because the Nano holds the last commanded values and runs its own watchdog, a stall or crash on the Pi results in the motor being stopped by the Nano rather than the robot continuing at its last commanded speed. That behaviour is implemented, not planned; see [Raspberry Pi and Arduino Communication](#raspberry-pi-and-arduino-communication).

## Programming Environment and Tools

| Platform | Language | Toolchain | Responsibilities |
|---|---|---|---|
| Raspberry Pi | Python 3 | Edited and run over SSH | Image processing, sensor integration, state management, steering calculation |
| Arduino Nano | C++, embedded | Arduino IDE | Deterministic real time control of motor PWM and servo steering commands |

## Development and Deployment

**Raspberry Pi.** Code is deployed over SSH, either over a direct Ethernet link or over a dedicated Wi-Fi hotspot. This gives low latency remote terminal management and fast code iteration during pit debugging, with no external monitor required.

**Arduino Nano.** Firmware is compiled and flashed with the standard Arduino IDE over a direct USB serial link.

**Startup indication.** Competition rules restrict external discrete LEDs, so boot and script execution are indicated using the Raspberry Pi's onboard green ACT LED, mapped through GPIO triggers. This confirms that the system has started. It does not convey system status beyond that.

A separate indicator exists on the Nano: `LED_BUILTIN` is driven HIGH by the serial watchdog when the link has timed out, and returns LOW when packets resume.

## Core Software Components

| File | Platform | Language | Purpose | Status |
|---|---|---|---|---|
| [`CameraProccesingUnit..py`](./CameraProccesingUnit..py) | Raspberry Pi | Python | Camera configuration, raw YUV422 capture, U and V channel colour masking, centroid calculation | Working pipeline with test threshold values |
| [`Transmissioncode.py`](./Transmissioncode.py) | Raspberry Pi | Python | Builds and writes the serial command string to the Nano, reads the reply | Working, with test scaffolding still present |
| [`Nanotransmissionreceiver.cpp`](./Nanotransmissionreceiver.cpp) | Arduino Nano | C++ | Serial receive, packet parse, command state, watchdog failsafe | Parsing and failsafe implemented; actuator calls commented out |
| [`Servo.cpp`](./Servo.cpp) | Arduino Nano | C++ | Servo library setup and pulse range configuration | **Test routine.** Sweeps fixed angles; not the final steering control |
| [`MotorPWM.cpp`](./MotorPWM.cpp) | Arduino Nano | C++ | Software generated PWM on a digital pin | **Test implementation.** Not the final motor control |

Two of the five files are test routines rather than control software, and the receiver's actuator calls are not yet wired. The perception and communication layers are the parts that currently run.

## Raspberry Pi and Arduino Communication

The link uses **human readable ASCII strings rather than binary packets**. Strings are easier to read on a terminal, easier to debug when a value looks wrong, and easier to modify when a field changes. The cost is a small reduction in efficiency and speed, accepted deliberately in exchange for development simplicity.

### Packet structure

```
$<servoAngle>,<motorSpeed>\n
```

| Element | Value | Purpose |
|---|---|---|
| Start marker | `$` | Identifies the beginning of a valid payload |
| Field 1 | `servoAngle` | Target steering angle |
| Delimiter | `,` | Separates the two fields |
| Field 2 | `motorSpeed` | Target motor speed |
| Terminator | `\n` | Marks the end of the payload |

### Raspberry Pi transmission

From [`Transmissioncode.py`](./Transmissioncode.py), using `pyserial` on `/dev/ttyUSB0` at 115200 baud with `timeout=0`:

```python
command_string = f"${ServoAngle},{MotorPWM}\n"   # string formation
ser.write(command_string.encode('utf-8'))

if ser.in_waiting > 0:
    response = ser.readline().decode('utf-8').strip()
```

A `time.sleep(0.1)` loop delay is present, noted in the source as accounting for frame rate and still to be tuned.

### Arduino parsing

From [`Nanotransmissionreceiver.cpp`](./Nanotransmissionreceiver.cpp). `Serial.begin(115200)` matches the Pi, and `Serial.setTimeout(2)` keeps stream reads from dragging the main loop. Characters are accumulated one at a time until the newline arrives:

```cpp
while (Serial.available() > 0) {
    char incomingChar = (char)Serial.read();
    if (incomingChar == '\n') {
        parseControlString(inputBuffer);
        inputBuffer = "";
    } else {
        inputBuffer += incomingChar;
    }
}
```

The parser validates the header, splits on the first comma and converts both fields:

```cpp
if (data.startsWith("$")) {
    data.remove(0, 1);
    int commaIndex = data.indexOf(',');
    if (commaIndex != -1) {
        servoAngle = data.substring(0, commaIndex).toInt();
        motorSpeed = data.substring(commaIndex + 1).toInt();
        lastPacketTime = millis();
        Serial.println("OK");
    }
}
```

Startup defaults are `servoAngle = 90`, the centre position, and `motorSpeed = 0`, stopped. A successful parse returns `OK` to the Pi.

### Watchdog failsafe

```cpp
if (millis() - lastPacketTime > TIMEOUT_MS) {   // TIMEOUT_MS = 200
    motorSpeed = 0;
    digitalWrite(LED_BUILTIN, HIGH);
} else {
    digitalWrite(LED_BUILTIN, LOW);
}
```

If no valid packet arrives within 200 ms, the drive throttle is cut to zero and the built in LED lights as a visual warning. `lastPacketTime` only refreshes on a successful parse, so a corrupted or malformed stream triggers the failsafe just as a disconnected cable would. This is the mechanism that makes the Pi's non deterministic timing safe to build on.

## Computer Vision System

The vision system trades resolution for processing frequency, so that the control loop stays responsive at speed.

```
        [ Raw camera feed ]
                 |
                 v
     [ YUV422 colour space capture ]
                 |
                 v
    [ Discard Y channel (luminance) ]
                 |
                 v
 [ Apply threshold masks on U and V channels ]
                 |
                 v
  [ NumPy vectorised pixel mean (centroid X, Y) ]
                 |
                 v
   [ Calculate relative angle and distance scale ]
```

The first four stages are implemented in [`CameraProccesingUnit..py`](./CameraProccesingUnit..py). The final stage, relative angle and distance scale, is designed but not yet written.

**Framing.** The pipeline document specifies QQVGA at 70 FPS. The current source configures:

```python
config = picam2.create_video_configuration(
    main={"size": (160, 140),
          "format": "YUV422" }  # QQVGA at raw yuv422 due to the weak single core processor of the Pi Zero W
)
```

The in-code comment gives the reason for the low resolution and the raw format directly: the single core processor of the Pi Zero W. No frame rate is set explicitly in the current source.

**Why not BGR or HSV.** Converting every frame to another colour space costs processing time the Pi Zero W does not have. Capturing raw YUV422 skips the conversion entirely, and because U and V are already the chrominance channels, a colour mask can be built by indexing into the array rather than transforming it first.

**Uses.** The camera provides block detection, corner line detection, turning decisions and obstacle detection.

**OpenCV.** OpenCV appears in the dependency research as intended for colour masking in the main code, and is listed among the Raspberry Pi libraries. It is **not imported by any current source file**. All processing implemented today is NumPy only.

## YUV422 Colour Detection

Implemented in [`CameraProccesingUnit..py`](./CameraProccesingUnit..py).

**1. Capture and channel extraction.** The frame arrives as raw YUV422 with channel indices `y = 0`, `u = 1`, `v = 2`. The Y channel is not read at all for this step:

```python
frame_yuv  = picam2.capture_array("main")
u_channel  = frame_yuv[:, :, 1]   # Slicing via numpy (Index: y-0, u - 1, v - 2)
v_channel  = frame_yuv[:, :, 2]
```

**2. Boolean mask.** Both chroma channels are tested against minimum and maximum bounds in a single vectorised expression:

```python
matching_indices = (u_channel >= u_min) & (u_channel <= u_max) & \
                   (v_channel >= v_min) & (v_channel <= v_max)
```

**3. Matching pixel positions.**

```python
y_positions, x_positions = np.where(matching_indices)
```

**4. Noise gate.** A region is only accepted above a pixel count. The source notes that both arrays are the same length, so only one is tested:

```python
if len(y_positions) > 30:
```

**5. Centroid.** The centre of the detected region is the arithmetic mean of the matching pixel coordinates:

```python
center_x = int(np.mean(x_positions))
center_y = int(np.mean(y_positions))
```

This returns the centroid without contour fitting or blob analysis, which is what keeps the pipeline fast enough to run on this hardware.

**Threshold values are test values.** The current bounds are `u_min, u_max = 90, 110` and `v_min, v_max = 140, 160`, marked in the source as being purely for testing purposes. They are **not finalised competition values**, and the file carries a single range pair rather than separate calibrated red and green sets. Dedicated red and green calibration sets are an open development item.

**Camera alignment.** The camera module is fixed along the chassis centreline, so the centre of a pillar aligns with the camera's central reference and the frame centreline can act as the 0° reference for relative angle.

## Open Challenge Strategy

```
Lane centering between walls, biased to the inner wall
                      |
                      v
          Corner line detection (camera)
                      |
                      v
             Corner line counting
                      |
                      v
              11 lines counted
                      |
                      v
   Camera navigation yields to encoder odometry
                      |
                      v
    Drive a pre-calculated distance, then full stop
```

**Lane centering.** The control algorithm holds the vehicle centred between the inner and outer track walls, with a slight algorithmic bias towards the inner boundary wall to optimise cornering radii.

**Lap counting and stop condition.** Lap progression is monitored by counting corner marker lines through the camera. Once 11 corner lines have been detected, the system changes state: camera navigation yields to encoder odometry, which drives the vehicle a pre-calculated physical distance before bringing it to a full stop.

**Status: planned.** The lane centering logic, corner line detection, the lap counter and the odometry handover are described in the navigation research and are not present in the current source files. The camera colour detection that they will build on is implemented.

## Obstacle Challenge Strategy

**Detection.** Red and green pillars are identified by the U and V channel mask described above, and their centroid is the mean position of the matching pixels.

**Relative angle.** The camera is fixed along the chassis centreline. The pixel distance between a detected pillar's centroid and the frame centreline represents the relative angular offset of that obstacle, with θ = 0° at true centre.

**Colour dependent avoidance.** The obstacle's colour and its relative angle together determine which side the robot passes on.

**Dynamic steering angle reduction.** The target avoidance angle between the chassis and the pillar decreases linearly as the pillar's pixel footprint increases in the frame, which indicates closer proximity. The effect is a smooth sweeping curve around a pillar rather than an abrupt late swerve. No equation for this relationship exists in the source or the research documents.

**Steering response.** Corrections are applied through the PID controlled servo.

**Status.** Detection and centroid calculation are implemented. Relative angle calculation, the size to angle reduction and the avoidance behaviour are planned and not present in the current source.

## PID Steering Control

A PID controller governs the steering servo. Its purpose is to reduce steering error and produce controlled corrections: enough response to reach the required steering position, without under correcting and drifting wide or over correcting and oscillating. The input is the obstacle centroid produced by the colour detection stage.

**Status: not implemented.** The PID loop and the reference angle calculation are listed as modules still to be written. The camera source refers to them explicitly, noting that the centre point exists for the PID avoidance algorithm and that the PID and reference angle systems belong in separate files. No gain values exist in any source or research file, and none are stated here.

## Odometry

The rotary encoder tracks physical movement. Its documented roles are:

* **Parking**, where positioning accuracy matters more than visual reference
* **Movement and distance estimation** during navigation
* **Final stopping behaviour** in the Open Challenge, taking over from camera navigation after the eleventh corner line and driving a pre-calculated distance to the stop point

Odometry is handled on the Raspberry Pi.

**Status: not implemented.** No encoder reading or odometry code exists in the current source files. The encoder hardware and its wiring are documented in the [Schemes](../schemes/README.md) documentation. No distance conversion or encoder calculation is stated here, because none exists yet.

## ToF-Based Safety and Positioning

The Time-of-Flight array provides spatial safety. It continuously monitors close proximity and acts as a fail-safe override: if the vehicle approaches a wall, the ToF reading forces immediate corrective steering, **overriding camera input**. This inversion of the normal priority is the point of the sensor. The camera drives the robot in open running, but a wall at close range is a situation where the camera's judgement is not allowed to win.

Documented roles:

* Parking
* Open Challenge navigation
* Wall distance estimation
* Collision protection
* Supporting or overriding camera based decisions

ToF sensors are read by the Raspberry Pi.

**Status: not implemented.** No ToF reading or override logic exists in the current source files.

## Sensor Fusion

Sensor inputs are merged dynamically according to environmental context and priority level rather than blended at fixed weights.

| Sensor | Primary role | Fusion and priority |
|---|---|---|
| **Camera** | Primary navigation | Calculates relative target angles for cornering, pillar detection and track colour lines. Holds primary control during open track driving. |
| **Rotary encoder** | Odometry and distance | Tracks precise physical movement for accurate parking manoeuvres and to determine final lap completion. |
| **Time-of-Flight** | Spatial safety net | Continuously monitors close proximity. Acts as a fail-safe override forcing immediate corrective steering when the vehicle approaches a wall, overriding camera input. |

The hierarchy is contextual: the camera leads on open track, the encoder leads where position matters more than vision, and the ToF array can pre-empt both when a collision is imminent.

**Status: planned.** This is the designed architecture. None of the three fusion paths are implemented in the current source, and no arbitration logic exists yet. A BNO085 IMU is present in the robot hardware, but it is not assigned a role in the sensor fusion architecture research and no IMU code exists in this folder.

## Motor Control

From [`MotorPWM.cpp`](./MotorPWM.cpp). **This is a test implementation, not the final motor control.**

PWM is generated in software by driving the pin directly, rather than using `analogWrite`:

```cpp
void motorPWM(float a) {
  int highTimeMs = static_cast<int>(a * 1000.0);
  int lowTimeMs  = static_cast<int>((1.0 - a) * 1000.0);

  digitalWrite(MOTOR_PIN, HIGH);
  delay(highTimeMs);

  digitalWrite(MOTOR_PIN, LOW);
  delay(lowTimeMs);
}
```

| Property | Value |
|---|---|
| Pin | 9 |
| Method | Software generated PWM using `digitalWrite` and `delay` |
| Input | `a`, a duty fraction between 0 and 1 |
| High period | `a × 1000` ms |
| Low period | `(1 - a) × 1000` ms |
| Resulting period | 1000 ms |
| Test value | `TimeOff = 0.15`, giving a 15% duty cycle |
| Serial | 9600 baud, for debug output |

Two limitations follow directly from the code as written. The period is one second, which is a test frequency rather than a drive frequency. And because the routine uses blocking `delay` calls, the loop cannot do anything else while a PWM phase is in progress. Both are consequences of this being a standalone test file; the motor routine that will run in the final firmware has to be called from the receiver's main loop alongside the serial handling and the watchdog.

## Steering Servo Control

From [`Servo.cpp`](./Servo.cpp). **This is a travel test routine, not the final steering control.**

```cpp
#include <Servo.h>
Servo myServo;
const int SERVO_PIN = 9;

// Attach the servo and unlock the extended 600us to 2400us pulse limits
myServo.attach(SERVO_PIN, 600, 2400);
```

| Property | Value |
|---|---|
| Library | Arduino `Servo` |
| Pin | 9 |
| Pulse range | 600 µs to 2400 µs, the extended range |
| 0° | 600 µs |
| 90° | 1500 µs, centre |
| 180° | 2400 µs |
| Serial | 9600 baud, for debug output |

The extended pulse range is unlocked deliberately: the default Arduino range is narrower, and using the full 600 to 2400 µs span gives the steering the widest travel the servo can deliver, which matters on a short wheelbase where a small angular range would limit the turning circle.

The current `loop()` sweeps to 0°, 90° and 180° with two second delays between them. That verifies mechanical travel and the pulse mapping. It is not steering control.

**Relationship to the higher level command.** In the final firmware the `servoAngle` value parsed from the serial packet is what will be written to the servo. That call currently exists as a commented placeholder in the receiver:

```cpp
// --- ACTUATOR RUN ROUTINE GOES HERE ---
// analogWrite(motorPin, abs(motorSpeed));
// steeringServo.write(servoAngle);
```

## Software Development Philosophy

The principles below are drawn from the design decisions visible in the research and the source, not stated as generic goals.

**Simple algorithms where simple is sufficient.** The vision pipeline is deliberately a NumPy channel mask, not a computer vision framework. Contour fitting and blob analysis were skipped in favour of a boolean mask and a mean, because that returns the centroid in milliseconds on hardware that could not afford the alternative.

**Match the platform to the task.** Perception on the Pi, deterministic actuator timing on the Nano. Neither platform is asked to do the thing it is bad at.

**Readability and debuggability over efficiency, where the cost is small.** The serial protocol uses ASCII strings rather than binary specifically so a human can read the traffic, at a known and accepted cost in speed.

**Practical constraints drive the design.** The camera resolution and raw format are chosen because of the Pi Zero W's single core. The framing decision is documented in the source itself, at the line where it is made.

**Iterative development, honestly tracked.** Test files, placeholder values and TODO comments are left visible in the source rather than removed, and the open items are tracked as a list rather than tidied away.

## Engineering Challenges and Solutions

### SSH access to the Raspberry Pi

**Challenge.** SSH over Wi-Fi through VS Code could not be made to work despite extended effort. Without SSH there was no way to test the code at all, because most of the libraries the code depends on only run on the Raspberry Pi itself.

**Approach.** Multiple solutions were attempted over hours before the approach was changed rather than continued.

**Solution.** Wi-Fi was dropped entirely in favour of Ethernet. It was later found that a hotspot configured to WPA2 on an older phone was the only way to get the Pi Zero W to connect to a network at all.

**Result.** Deployment now runs over SSH via direct Ethernet, with the WPA2 hotspot available for network connectivity. SSH itself still requires the direct Ethernet connection to a laptop.

### Obstacle detection performance

**Challenge.** The obstacle detection algorithm worked, but it was slow, reported a low frame rate, struggled under varying lighting, and overloaded the CPU of a test Raspberry Pi 3, which is considerably more powerful than the Zero W the robot actually carries. It also drew bounding boxes above the obstacles rather than on them.

**Approach.** The problem was traced to the inefficiencies in the visual processing pipeline

**Solution.** Higher resolutions were dropped for QQVGA, colour format was changed from BGR and HSV to YUV422 as YUV is raw data from the camera and separates luminance (y) from u and v, therefore making colour data immune to bad lighting, a problem that affects BGR. HSV can be used but it requires a conversion to BGR first, squandering our limited compute.

**Result.** We can now achieve a comfortable 30-70fps without light issues.

## Implementation Status

An explicit summary, so that nothing in this document is mistaken for more than it is.

| Capability | Status |
|---|---|
| Camera capture, YUV422, U and V masking, centroid | **Implemented**, with test threshold values |
| Serial protocol, Pi transmission side | **Implemented**, with test scaffolding present |
| Serial protocol, Nano parsing side | **Implemented** |
| Watchdog failsafe on the Nano | **Implemented** |
| Servo pulse range configuration | **Implemented**, inside a test routine |
| Software PWM generation | **Test implementation only** |
| Actuator calls driven by received commands | **Not wired**, commented placeholders |
| Relative angle calculation | **Planned** |
| Dynamic steering angle reduction | **Planned** |
| PID steering loop | **Planned**, not written |
| Reference angle module | **Planned**, not written |
| Corner line detection and counting | **Planned** |
| Lane centering | **Planned** |
| Odometry and encoder reading | **Planned** |
| ToF reading and override logic | **Planned** |
| Sensor fusion arbitration | **Planned** |
| Parking sequence | **Planned** |

## Known Issues, Gaps and TODOs

### Hardware and baud conflicts

* **Pin allocation conflict.** Both [`Servo.cpp`](./Servo.cpp) and [`MotorPWM.cpp`](./MotorPWM.cpp) currently attempt to use pin 9.
* **Baud rate mismatch.** The standalone C++ test files open serial at 9600 baud, while [`Nanotransmissionreceiver.cpp`](./Nanotransmissionreceiver.cpp) operates at 115200 baud.

### Open development items

* **Integration.** Re-enable and wire the commented out actuator hardware calls in `Nanotransmissionreceiver.cpp` to the servo and motor routines.
* **PID system.** Write the standalone PID steering loop and the reference angle calculation modules.
* **Colour bounds.** Replace the temporary inline U and V test bounds with dedicated red and green calibration sets.
* **Transmission delay.** Tune the `time.sleep(0.1)` transmission loop delay against the real time camera frame rate.
* **Code cleanup.** Remove test scaffolding: the `input()` calls in the Python files, the terminal prints in the vision module, and the test print statements.
* **Optimisation.** Evaluate dropping the `center_y` calculation if the PID avoidance algorithm does not need it.

## Software Dependencies

### Python, Raspberry Pi

| Library | Purpose | In current source |
|---|---|---|
| `numpy` | Array slicing, boolean masks, `np.where`, `np.mean` | Yes |
| `picamera2` | Camera configuration and frame acquisition | Yes |
| `libcamera` | Camera stack | Yes |
| `time` | Frame timing and delay loops | Yes |
| `serial` (pyserial) | Serial bus communication with the Arduino | Yes |
| `opencv` | Colour masking in the main code | **No.** Listed in the dependency research as intended for future use; not imported by any current source file |

### C++, Arduino Nano

| Library | Purpose | In current source |
|---|---|---|
| `Arduino.h` | Core microcontroller function definitions | Yes |
| `Servo.h` | Servo pulse generation | Yes |
| Built in `Serial` | Serial bus communication and debugging | Yes |

## File Structure

### Source files

| File | Type | Platform | Purpose |
|---|---|---|---|
| [`CameraProccesingUnit..py`](./CameraProccesingUnit..py) | Python | Raspberry Pi | Camera capture and YUV422 colour detection with centroid output |
| [`Transmissioncode.py`](./Transmissioncode.py) | Python | Raspberry Pi | Serial command transmission to the Arduino Nano |
| [`Nanotransmissionreceiver.cpp`](./Nanotransmissionreceiver.cpp) | C++ | Arduino Nano | Serial receive, parsing, command state and watchdog failsafe |
| [`Servo.cpp`](./Servo.cpp) | C++ | Arduino Nano | Servo library setup and travel test |
| [`MotorPWM.cpp`](./MotorPWM.cpp) | C++ | Arduino Nano | Software PWM test implementation |

### Research and design documents

| Document | Contents |
|---|---|
| [`Core Software Components.pdf`](./Core%20Software%20Components.pdf) | Language choices, core libraries and the functional task distribution between the two platforms |
| [`Computer Vision System & Processing Pipeline.pdf`](./Computer%20Vision%20System%20&%20Processing%20Pipeline.pdf) | Vision pipeline stages, framing decisions and the reasoning behind raw YUV422 processing |
| [`Navigation Strategies & Algorithms.pdf`](./Navigation%20Strategies%20&%20Algorithms.pdf) | Open Challenge lane centering and stop condition, Obstacle Challenge centering and dynamic steering angle reduction |
| [`Sensor Fusion Architecture.pdf`](./Sensor%20Fusion%20Architecture.pdf) | Sensor roles and the contextual priority hierarchy between camera, encoder and ToF |
| [`Build & Deployment Process.pdf`](./Build%20&%20Deployment%20Process.pdf) | SSH deployment, Arduino IDE flashing and startup indication |
| [`Software Dependencies.pdf`](./Software%20Dependencies.pdf) | Python and C++ library dependencies and their purposes |
| [`Engineering Challenges & Solutions.pdf`](./Engineering%20Challenges%20&%20Solutions.pdf) | The SSH access problem and the obstacle detection performance problem, with how each was resolved |
| [`Known Issues, Gaps & TODOs.pdf`](./Known%20Issues,%20Gaps%20&%20TODOs.pdf) | Pin and baud conflicts and the current open development items |

## Technical Documentation

| Area | Documentation |
|---|---|
| Electrical design, wiring and power | [Schemes](../schemes/README.md) |
| Mechanical design and manufacturing files | [Models](../models/README.md) |
| Component references and research | [Other](../other/README.md) |
| Vehicle photographs | [Vehicle photos](../v-photos/README.md) |

*Team MadEngineerz, WRO 2026 Future Engineers*

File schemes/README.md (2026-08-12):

# Schemes Documentation

Complete electrical documentation for the MadEngineerz WRO 2026 Future Engineers robot. This folder holds the wiring schematic, the power system analysis, the electrical design philosophy, and the pinouts, reference schematics, component images and manufacturer datasheets for every electronic part in the vehicle.

## Contents

* Electrical Design Philosophy
* Complete Bill of Materials
* Complete Wiring System
* Power Management System
* Cable Management
* Custom Perfboard-Based Electronics
* Component-Specific Engineering
* Time-of-Flight Sensor System
* Motor System
* TB6612FNG Motor Driver
* EMAX ES08MA II Steering Servo
* BNO085 IMU
* MP1584 Voltage Regulator
* TCA9548A I²C Multiplexer
* Pinout and Schematic Reference
* Datasheets
* Electrical Documentation Repository
* Technical Documentation

## Electrical Design Philosophy

Full document: [`Electrical_design_Philosophy.pdf`](./Electrical_design_Philosophy.pdf)

### 1. Power architecture and battery selection

**Cell chemistry.** A Lithium Polymer pack was selected to optimise the vehicle's power to weight ratio. LiPo provides the high discharge rate needed to absorb rapid motor acceleration without voltage drops, in a compact physical volume that suits the tight chassis constraints.

**Thermal and electrical efficiency.** Logic and sensing units are supplied through a high efficiency switching buck converter rather than a linear regulator such as an LM7805. Switching regulation significantly reduces thermal dissipation and avoids wasting energy as heat, which extends battery operational life across testing and competition runs.

**Driver architecture.** A compact H-bridge driver was chosen in preference to a full motor shield. This reduced the board footprint and simplified wire routing, and the body diodes inside the H-bridge handle inductive kickback from the motor, removing the need for external flyback diodes.

### 2. Noise isolation and topology

**Inherent power isolation.** The architectural layout naturally separates clean logic lines from high noise inductive loads. The high noise components, meaning the motor and the driver, draw directly from the LiPo pack or from dedicated buck converter lines rather than sharing a path with the logic supply.

**Signal protection.** With the high current paths isolated from the central logic, the low voltage control signals stay protected from electromagnetic interference and ground bounce. This matters specifically for the PWM motor drive commands and the high frequency rotary encoder pulses, both of which are corrupted by exactly the kind of noise a motor generates.

### 3. Sensor fusion and odometry strategy

A complementary sensor suite was implemented to eliminate visual blind spots and maintain position tracking.

```
                    +---------------------------+
                    |    Primary Visual Feed    |
                    |      (RPi + Camera)       |
                    +-------------+-------------+
                                  |
                +-----------------+-----------------+
                |                                   |
                v                                   v
   +---------------------------+       +---------------------------+
   |   Blind Spot Clearance    |       |   Vehicle State & Pos.    |
   |  (Time-of-Flight Arrays)  |       |  (IMU + Rotary Encoder)   |
   +---------------------------+       +---------------------------+
```

**Visual perception with proximity sensing.** The camera provides long range track layout recognition but suffers localised blind spots directly around the vehicle bumpers. Time-of-Flight distance sensors are paired with it to cover those blind spots and to provide accurate distance to wall measurements.

**Odometry and dead reckoning.** To compensate for momentary visual occlusion or lighting variation, the IMU supplies heading and angular velocity while the rotary encoder supplies wheel rotation and linear distance. Both run continuously, giving a steady multi sensor estimate of vehicle state that does not depend on the camera being usable at that instant.

### 4. Communication and serviceability

**Processing bus.** UART was selected for inter board communication between the main vision processor and the low level real time controller. UART is a lightweight point to point serial connection that avoids the master and slave overhead, the addressing and the driver complexity that I²C or SPI would bring to a link with only two endpoints.

**Modular cabling.** All sensors, power rails and actuators use polarised JST connectors. This modularity allows a component to be swapped instantly during troubleshooting in pit conditions, without any re-soldering.

### 5. Accessible compute bus and wiring

All compute components, meaning the Raspberry Pi Zero and the Arduino Nano, along with the multiplexer and the IMU, are placed at the top of the vehicle in a detachable manner. This gives direct access for debugging, wiring, last minute changes and flashing code. The wiring and these components are carried on a perfboard.

## Complete Bill of Materials

| Component | Image | Quantity | Description |
|---|---|---:|---|
| **Raspberry Pi Zero 2 W** |  | 1 | Main vision processor. Hosts the camera and the I²C bus, and links to the Arduino Nano over UART. |
| **Raspberry Pi Camera** |  | 1 | Primary visual sensor for long range track layout recognition. Connects to the Pi over the camera ribbon cable. |
| **Arduino Nano** |  | 1 | Low level real time controller. Drives the motor driver inputs and handles the encoder pulses. |
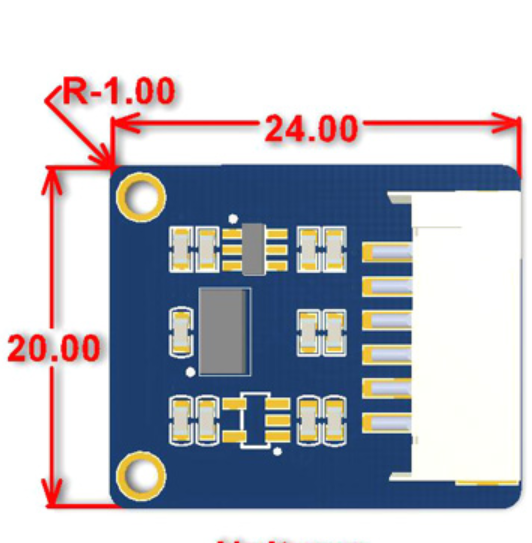
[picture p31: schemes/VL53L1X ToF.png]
| **VL53L1X** |  | 1 | Time-of-Flight ranging sensor, up to 400 cm, typical full field of view 27°. |
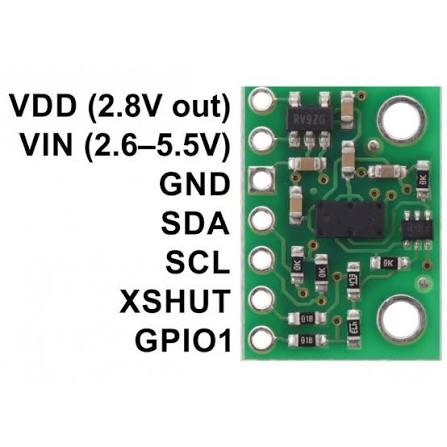
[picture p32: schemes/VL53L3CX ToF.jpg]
| **VL53L3CX** |  | 3 | Time-of-Flight ranging sensor with multi target detection, typical full field of view 25°. |
| **BNO085** |  | 1 | 9 DoF orientation IMU with on board sensor fusion. Supplies heading and angular velocity. |
| **TCA9548A** |  | 1 | 8 channel I²C multiplexer. Gives each ranging sensor its own bus channel. |
| **TB6612FNG** |  | 1 | H-bridge motor driver for the N20 drive motor. |
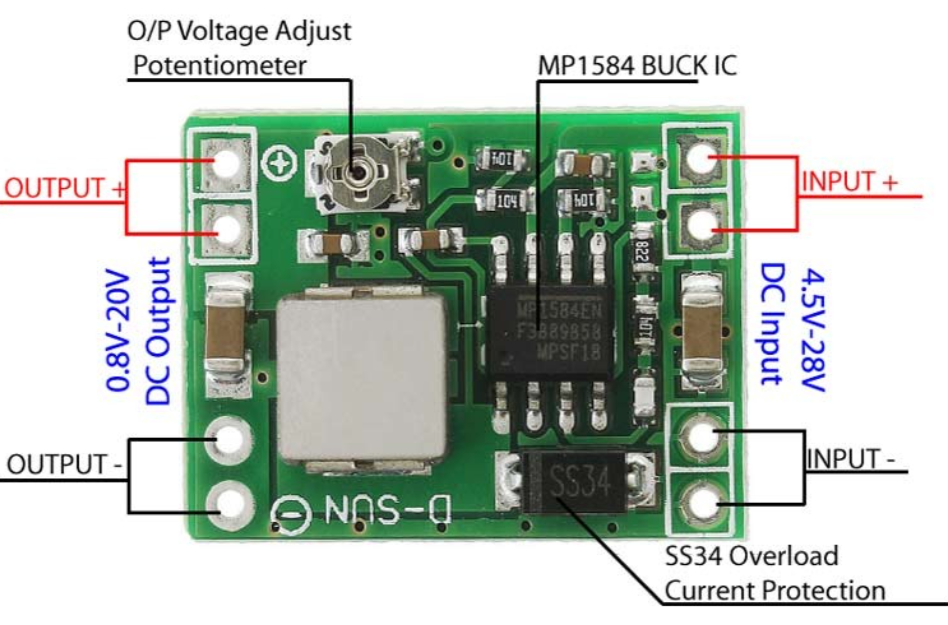
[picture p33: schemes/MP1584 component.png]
| **MP1584** |  | 1 | Step down switching buck converter producing the regulated logic rail. |
| **500 RPM N20 motor** |  | 1 | Metal gear DC motor with rotary encoder. Drives the rear axle. |
| **EMAX ES08MA II** |  | 1 | Metal gear micro servo. Steering actuator. |
| **Battery** |  | 1 | 2S LiPo pack. Sole power source for the vehicle. |

Component photographs for the TCA9548A, N20 motor, servo and battery are held in the [`other`](../other/) folder and referenced here rather than duplicated.

## Complete Wiring System

The complete wiring schematic is the source of truth for every electrical connection in the robot.

<p align="center">
  <a href="./WIRING.pdf"><strong>Open the complete wiring schematic &rarr; WIRING.pdf</strong></a>
</p>

### Electrical architecture

**Power input.** The 2S LiPo pack appears in the schematic with its positive terminal and its 0 V return. The pack feeds two things directly: the input side of the MP1584 buck converter, and the motor supply of the TB6612FNG.

**Voltage regulation.** The MP1584 is drawn with `VIN+` and `VIN-` on its input and `Vout+` and `Vout-` on its output. Its regulated output supplies the logic side of the system.

**Raspberry Pi Zero 2 W.** The Pi appears as its `J1` 40 pin GPIO header with the standard pin functions labelled, including the `+3V3` and `+5V` rails, both `GND` pins, `GPIO02/SDA1` and `GPIO03/SCL1` for I²C, `GPIO14/TXD0` and `GPIO15/RXD0` for UART, and the SPI, PWM and PCM capable pins. The header carries the I²C bus out to the multiplexer, and the +3V3 and +5V rails are distributed from it.

**Arduino Nano.** The Nano block shows a micro USB-B port and the `GPIO 5`, `GPIO 6`, `GPIO 8` and `GPIO 10` lines together with `VCC` and `GND`. A **MICROUSB BUS** block with separate `Data` and `PWR` lines sits between the Pi and the Nano, carrying both the serial link and the Nano's supply.

**Motor driver and motor.** The TB6612FNG block carries `VCC`, `GND`, `MOTOR VCC`, the `AIN1` and `AIN2` control inputs and the `AOUT1` and `AOUT2` motor outputs. `MOTOR VCC` comes from the pack side, while `VCC` is the logic supply. `AIN1` and `AIN2` are driven from the Nano's `GPIO 10` and `GPIO 6`. `AOUT1` and `AOUT2` run to the N20's `MOTOR PIN 1` and `MOTOR PIN 2`. The N20 block also carries `VCC` and `GND` for its encoder and the `C1` and `C2` encoder channels, which return to the Nano.

**Steering servo.** The `ES08MA II` block is drawn with three connections: `VCC`, `GND` and `PWM`.

**I²C devices.** The `TCA9548A` block carries `VCC`, `GND`, `SDA`, `SCL` and `RST` on its upstream side, the `A0`, `A1` and `A2` address pins, and the eight downstream channel pairs `SD0`/`SC0` through `SD7`/`SC7`. The ranging sensors are drawn as blocks with `VCC`, `GND`, `SCL` and `SDC`, each connecting to its own multiplexer channel rather than sharing one bus.

**Ground.** Common ground is the negative terminal of the LiPo pack, giving every device on the vehicle a single fixed voltage reference. This is what allows the I²C bus, the servo PWM line and the encoder pulses to be read consistently across devices sitting on different supply rails.

The schematic also carries a reference note pointing to `https://pinout.xyz/` for additional Raspberry Pi pin functions.

## Power Management System

Full document: [`Power System..pdf`](./Power%20System..pdf)

### Power distribution architecture

The distribution is deliberately simple. The 2S LiPo pack supplies the vehicle, and the buck converter together with the single board computer produces the lower rails. There is no further conversion stage.

| Rail | Source | Supplies |
|---|---|---|
| **7.4 V to 8.4 V** | LiPo pack, direct | Motor driver, buck converter input |
| **5 V** | Buck converter and the SBC/SBM | Raspberry Pi and Arduino Nano, sensors, motor driver power, servo motor |
| **3.3 V** | Raspberry Pi, over the camera ribbon cable | Camera. Many components, including all the ToF sensors and the I²C multiplexer, are compatible with both 3.3 V and 5 V |

**Common ground** is the negative terminal of the LiPo pack, providing a common fixed voltage reference for the whole system.

Two consequences follow from this topology. The motor driver is the only device that takes the raw pack voltage, so everything else sits behind the regulator and is insulated from the voltage sag the motor causes when it loads. And because most of the sensing hardware tolerates either 3.3 V or 5 V, the number of distinct rails stays at three rather than requiring separate regulation per sensor family.

### Power consumption analysis

Figures below are worst case estimates for an unideal scenario, taken from the power system document. They are calculated estimates rather than measured values.

| Hardware | Voltage | Current draw |
|---|---|---|
| Raspberry Pi Zero at 100% CPU capacity | 5 V | ~220 mA |
| Camera | 5 V | 200 to 225 mA |
| N20 motor | 7.4 V motor, 3.3 V or 5 V logic | 180 to 550 mA |
| Arduino Nano, UART connection to the Pi | 3.3 V | 30 to 50 mA |
| VL53L1X | 5 V to 3.3 V | 20 mA per sensor |
| VL53L3CX | 3.3 V to 5 V | 20 mA per sensor |
| TB6612FNG driver | 7.4 V for the motor, 5 V logic | 5 mA |
| TCA9548A | 3.3 V to 5 V | ~1 mA, negligible |
| **Total system** | mixed | **796 mA to 1.2 A** |

The dominant and most variable load is the motor, whose draw spans a range roughly three times wider than any other device. Current spikes occur mainly when the N20 is suddenly loaded, which in practice means starting from a standstill or striking an obstacle. Those events are expected to be rare, but the analysis accounts for them rather than assuming a steady load.

## Cable Management

The vehicle has a relatively large open central region between the upper and lower chassis sections. Cable management is built around that space rather than around dedicated routing hardware.

All wiring from the upper portion of the robot and all wiring from the lower portion meets in this central region. Because both halves terminate in the same place, the cabling is a set of short runs into one area instead of long runs across the vehicle, and the result is practical rather than elaborate:

* **Organisation.** Connections converge at one identifiable region, so a wire can be traced from either end without following it around the chassis.
* **Assembly.** The upper and lower sections are wired separately and joined at the centre, which means each half can be built and checked on its own.
* **Accessibility and maintenance.** Separating the two chassis sections exposes the whole cable run at once, so a connection can be reached without dismantling further.
* **Connecting upper and lower electronics.** The perfboard on the upper section is the landing point for the devices mounted below, and the central region is the path between them.
* **Clearance from mechanical systems.** Routing through the central region keeps cabling away from the steering linkage and the rear axle and gear pair, which are the only moving parts that could catch or chafe a wire.
* **Troubleshooting.** Faults are located by inspecting one region rather than the whole vehicle, and the JST connectors described in the design philosophy allow a suspect device to be disconnected there and swapped.

## Custom Perfboard-Based Electronics

The robot uses a **custom perfboard-based electrical system**. The perfboard carries the compute components and the interconnections between every module, and mounts to the upper chassis section as a detachable electronics deck.

This is an intentional engineering choice suited to how the robot was developed, not a claim that perfboard is better in general. A professionally manufactured PCB gives a more finalised and more compact result, and for a settled design it is the better answer. The difference is what happens when the design changes: a PCB change generally requires another board revision and another manufacturing cycle, whereas the perfboard circuit can be modified directly, in place, during development.

| Aspect | Professional PCB | Our perfboard system |
|---|---|---|
| Development | Fixed after manufacturing | Easily modified |
| Modification | Requires a board revision | Direct modification |
| Development cost | Higher for repeated revisions | Low |
| Hands-on experience | Lower | High |
| Component replacement | More difficult | Easier |
| Manufacturing | External fabrication | In-house |
| Flexibility | Lower after fabrication | High |

In practice this gives the project rapid development, low cost across repeated revisions, hands on soldering and circuit building experience for the team, in-house manufacturing with no external dependency, straightforward component replacement and troubleshooting, and modularity that is genuinely practical because a module can be lifted out and tested on its own.

### Device placement

Three devices are mounted on the perfboard itself:

* Raspberry Pi Zero 2 W
* Arduino Nano
* BNO085 IMU

Every other device connects to the perfboard from below, from wherever it is mounted in the chassis. This split follows the design philosophy's requirement that the compute components sit at the top of the vehicle in a detachable manner. The processors, the multiplexer and the IMU have no reason to sit anywhere but the deck, while the camera, the ranging sensors, the motor driver, the motor and the servo must sit where their function places them. Making the perfboard the single upper interconnection point means each distributed device needs one run up to a common landing rather than a web of connections between themselves.

The perfboard is a physical build rather than a drawn artefact, so it does not appear in the digital wiring schematic. It is documented here as the manufacturing approach that implements that schematic.

## Component-Specific Engineering

### Raspberry Pi Zero 2 W

<p align="center">
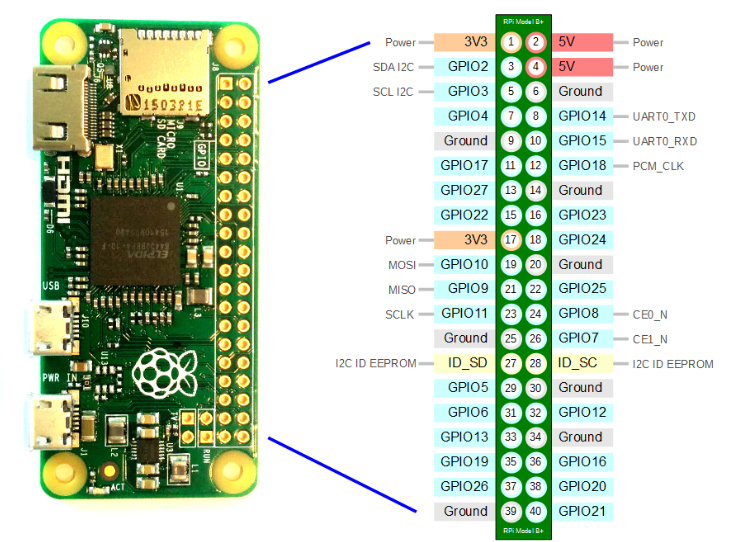
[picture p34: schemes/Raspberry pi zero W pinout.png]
  
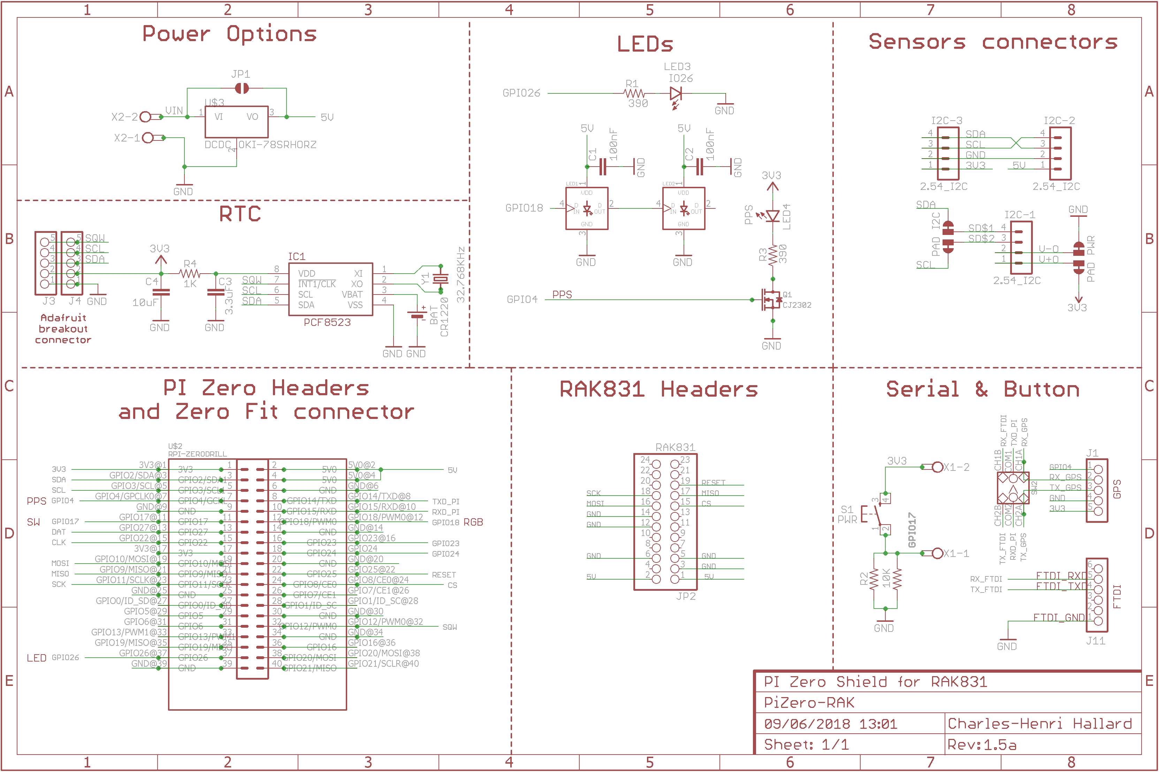
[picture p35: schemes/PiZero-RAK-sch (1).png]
  
</p>
<p align="center">
  <em>Raspberry Pi Zero GPIO pinout and board reference schematic, used to plan the header assignments for the I²C bus, the UART link and the power rails.</em>
</p>

**Role.** Main vision processor. It hosts the camera, drives the I²C bus through the multiplexer, and communicates with the Arduino Nano over UART.

**Header connections as drawn in the wiring schematic.**

| Pin | Function | Connection |
|---|---|---|
| `+3V3` | 3.3 V rail | Distributed from the header |
| `+5V` | 5 V rail | Distributed from the header |
| `GND` (two pins) | Ground | Common ground with the LiPo negative terminal |
| `GPIO02/SDA1` | I²C data | Upstream side of the TCA9548A |
| `GPIO03/SCL1` | I²C clock | Upstream side of the TCA9548A |
| `GPIO14/TXD0` | UART transmit | Serial link to the Arduino Nano |
| `GPIO15/RXD0` | UART receive | Serial link to the Arduino Nano |

The schematic labels the remaining header pins with their standard functions, including the SPI group (`GPIO09/SPI0.MISO`, `GPIO10/SPI0.MOSI`, `GPIO11/SPI0.SCLK`, `GPIO07/SPI0.CE1`, `GPIO08/SPI0.CE0`), the PWM pins (`GPIO12/PWM0`, `GPIO13/PWM1`), the PCM group and the `ID_SDA` and `ID_SCL` pins.

**Datasheet:** [`Raspberry pi 0 datasheet.pdf`](./Raspberry%20pi%200%20datasheet.pdf)

### Raspberry Pi Camera

<p align="center">
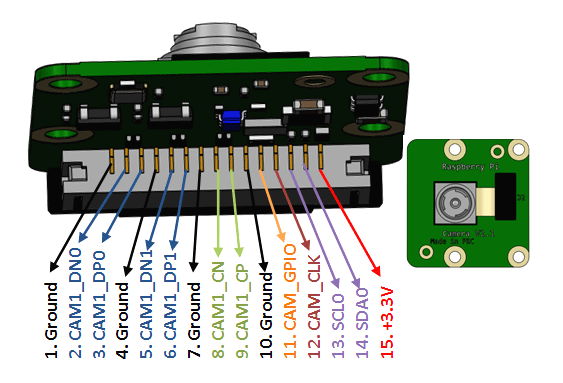
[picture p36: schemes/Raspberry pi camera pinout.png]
  
</p>
<p align="center">
  <em>Camera connector pinout. The camera attaches to the Pi over the ribbon cable, which also carries its 3.3 V supply.</em>
</p>

**Role.** Primary visual sensor. It provides long range recognition of the track layout, while the ToF array covers the blind spots immediately around the vehicle that the camera cannot see.

**Power.** 3.3 V, supplied by the Raspberry Pi over the ribbon cable.

**Datasheets:** [`raspberry-pi-camera datasheet.pdf`](./raspberry-pi-camera%20datasheet.pdf) · [`RP-008969-SD-3-Raspberry Pi Camera Module 3 Reference Schematic.pdf`](./RP-008969-SD-3-Raspberry%20Pi%20Camera%20Module%203%20Reference%20Schematic.pdf)

### Arduino Nano

<p align="center">
  
</p>
<p align="center">
  <em>Arduino Nano, the low level real time controller handling motor drive signals and encoder pulses.</em>
</p>

**Role.** Low level real time controller. UART was chosen for its link to the Pi because a two endpoint connection gains nothing from I²C or SPI addressing and arbitration.

**Connections as drawn in the wiring schematic.**

| Pin | Function | Connection |
|---|---|---|
| `VCC` | Supply | Logic rail |
| `GND` | Ground | Common ground |
| micro USB-B port | Data and power | MICROUSB BUS block, linking to the Raspberry Pi |
| `GPIO 10` | Motor control output | TB6612FNG `AIN1` / `AIN2` |
| `GPIO 6` | Motor control output | TB6612FNG `AIN1` / `AIN2` |
| `GPIO 5` | Control line | Motor and servo control group |
| `GPIO 8` | Control line | Motor and servo control group |

**Datasheets:** [`A000005-datasheet.pdf`](./A000005-datasheet.pdf) · [`A000005-full-pinout.pdf`](./A000005-full-pinout.pdf)

## Time-of-Flight Sensor System

Current configuration: **1 × VL53L1X** and **3 × VL53L3CX**.

<p align="center">
  
  
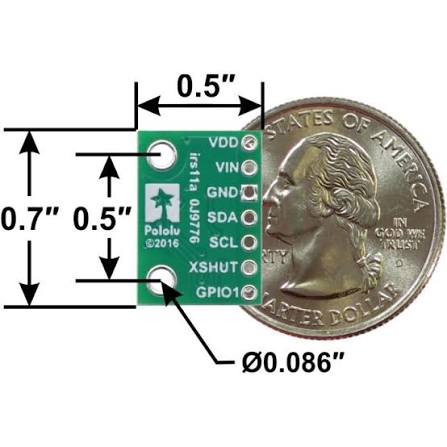
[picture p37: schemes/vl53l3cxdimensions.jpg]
  
</p>
<p align="center">
  <em>VL53L1X and VL53L3CX ranging sensors, with the VL53L3CX package dimensions that govern how the sensors are mounted in the chassis.</em>
</p>

**Role in the architecture.** The camera handles long range track layout recognition but has localised blind spots directly around the vehicle bumpers. The ToF array covers those blind spots and provides the distance to wall measurements the camera cannot supply. In the navigation software the ToF sensors carry the highest authority when an immediate risk of collision is detected, and they are used for parking, crash prevention and final positioning.

### ToF sensor comparison

Specifications below are taken from the manufacturer datasheets in this folder.

| Characteristic | VL53L1X | VL53L3CX |
|---|---|---|
| Quantity | 1 | 3 |
| Ranging distance | Up to 400 cm | Up to 300 cm+ with full field of view |
| Typical full field of view | 27° | 25° |
| Ranging frequency | Up to 50 Hz | Not stated in the datasheet summary |
| Measurement technology | SPAD receiving array with integrated lens, 940 nm Class 1 laser | Histogram based direct ToF, 940 nm VCSEL |
| Distinguishing features | Programmable region of interest, both size and position, allowing the field of view to be reduced and multizone operation controlled from the host | Multi target detection and measurement, short distance high accuracy linearity, immunity to cover glass crosstalk and fingerprint smudge at long distance, dynamic smudge compensation |
| Interface | I²C | I²C up to 1 MHz, with Xshutdown and interrupt GPIO |
| Package size | 4.9 × 2.5 × 1.56 mm | 4.4 × 2.4 × 1.0 mm |
| Supply compatibility | 3.3 V and 5 V | 3.3 V and 5 V |

**Bus architecture.** Both parts are I²C devices, and identical ranging sensors cannot share a single bus without address management. Every sensor is therefore given its own downstream channel on the TCA9548A, as drawn in the wiring schematic, with `VCC`, `GND`, `SCL` and `SDC` on each block.

**Datasheets:** [`VL53L1X.pdf`](./VL53L1X.pdf) · [`VL53L3CX.PDF`](./VL53L3CX.PDF) · [`VL53LX-Distance-Sensor-Schematic.pdf`](./VL53LX-Distance-Sensor-Schematic.pdf)

## Motor System

<p align="center">
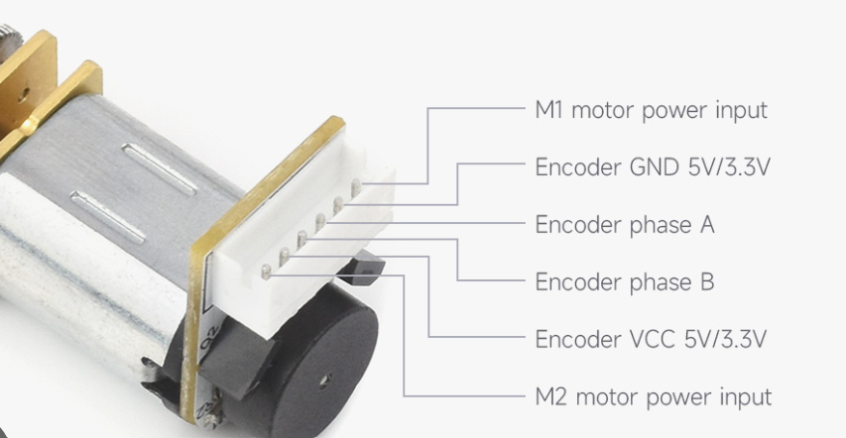
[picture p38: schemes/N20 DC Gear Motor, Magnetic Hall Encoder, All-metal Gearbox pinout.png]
  
</p>
<p align="center">
  <em>N20 motor and Hall effect encoder pinout, covering both the motor terminals and the encoder outputs.</em>
</p>

**Role.** Single drive motor for the rear axle. The mechanical drivetrain, gear ratio and speed analysis are documented in the [Models](../models/README.md) documentation; this section covers the electrical integration only.

**Power.** 7.4 V for the motor, with 3.3 V or 5 V logic for the encoder. Estimated draw is 180 to 550 mA, the widest range of any device in the system.

**Connections as drawn in the wiring schematic.**

| Pin | Function | Connection |
|---|---|---|
| `MOTOR PIN 1` | Motor terminal | TB6612FNG `AOUT1` |
| `MOTOR PIN 2` | Motor terminal | TB6612FNG `AOUT2` |
| `VCC` | Encoder supply | Logic rail |
| `GND` | Encoder ground | Common ground |
| `C1` | Encoder channel | Returned to the Arduino Nano |
| `C2` | Encoder channel | Returned to the Arduino Nano |

**Why the encoder path is isolated.** The design philosophy separates the high current motor path from the logic side precisely so that the high frequency encoder pulses on `C1` and `C2` are not corrupted by the motor's own switching noise or by ground bounce. The encoder is the vehicle's source of wheel rotation and linear distance for dead reckoning, so a corrupted pulse train degrades position tracking directly.

## TB6612FNG Motor Driver

<p align="center">
  
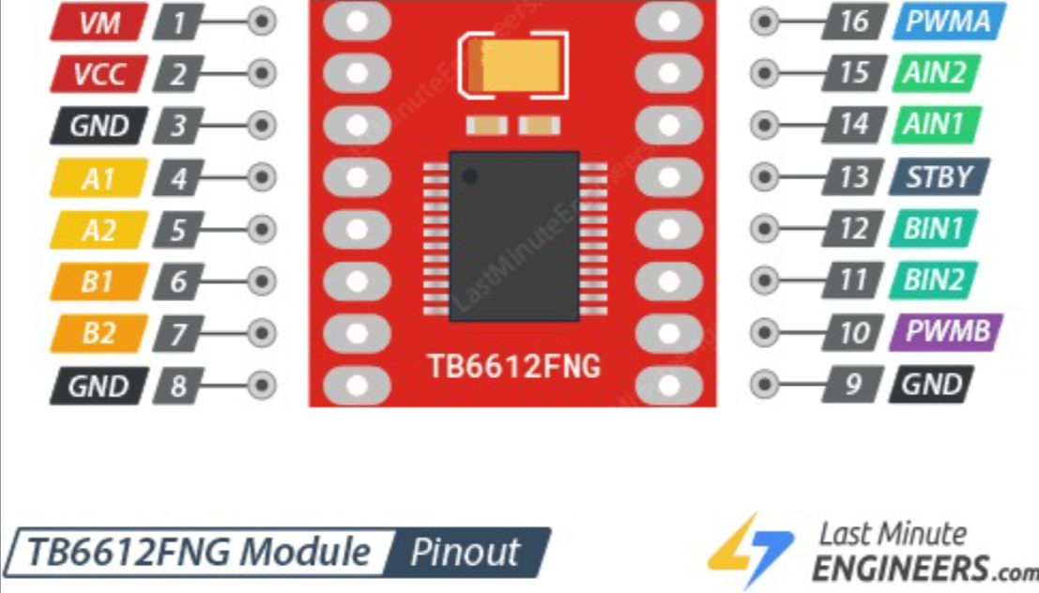
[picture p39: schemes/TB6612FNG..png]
  
</p>
<p align="center">
  <em>TB6612FNG motor driver module and its reference documentation.</em>
</p>

**Role.** H-bridge driver between the low level controller and the N20 motor. A compact driver was chosen in preference to a full motor shield to reduce footprint and simplify routing, and its internal body diodes absorb the inductive kickback from the motor, so no external flyback diodes are required.

**Connections as drawn in the wiring schematic.**

| Pin | Function | Connection |
|---|---|---|
| `MOTOR VCC` | Motor supply | LiPo pack, 7.4 V to 8.4 V |
| `VCC` | Logic supply | 5 V rail |
| `GND` | Ground | Common ground |
| `AIN1` | Control input | Arduino Nano, `GPIO 10` / `GPIO 6` |
| `AIN2` | Control input | Arduino Nano, `GPIO 10` / `GPIO 6` |
| `AOUT1` | Motor output | N20 `MOTOR PIN 1` |
| `AOUT2` | Motor output | N20 `MOTOR PIN 2` |

**Power architecture.** The separation of `MOTOR VCC` from `VCC` is what makes the isolation described in the design philosophy work: the motor current is drawn from the pack while the driver's logic side sits on the regulated rail with the rest of the control electronics.

**Estimated logic draw:** 5 mA.

**Datasheet:** [`TB6612FNG_datasheet_en_20121101.pdf`](./TB6612FNG_datasheet_en_20121101.pdf)

## EMAX ES08MA II Steering Servo

<p align="center">
  
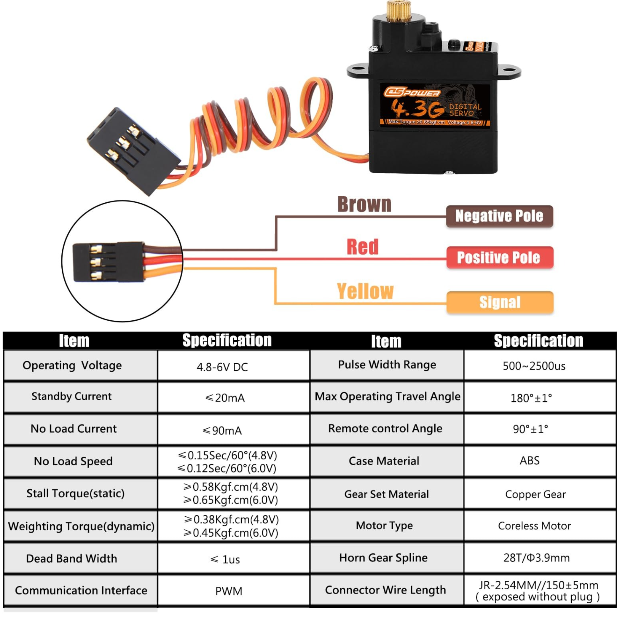
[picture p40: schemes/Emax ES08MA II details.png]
  
</p>
<p align="center">
  <em>EMAX ES08MA II metal gear micro servo and its reference details.</em>
</p>

**Role.** Steering actuator. It drives the steering linkage, whose Ackermann geometry is documented in the [Models](../models/README.md) documentation. This section covers the electrical integration only.

**Power.** 5 V rail.

**Connections as drawn in the wiring schematic.**

| Pin | Function | Connection |
|---|---|---|
| `VCC` | Supply | 5 V rail |
| `GND` | Ground | Common ground |
| `PWM` | Position command | Control side of the schematic |

**Datasheet:** [`54-ES08MA.pdf`](./54-ES08MA.pdf)

## BNO085 IMU

<p align="center">
  
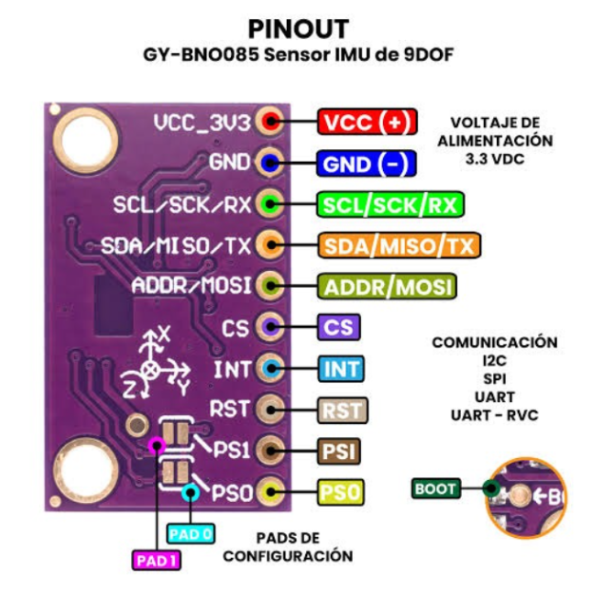
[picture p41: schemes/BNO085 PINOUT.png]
  
</p>
<p align="center">
  <em>BNO085 9 DoF orientation IMU breakout and its pinout.</em>
</p>

**Role.** The BNO085 supplies heading and angular velocity for the vehicle state estimate. It runs continuously alongside the rotary encoder so that position tracking survives momentary visual occlusion or lighting variation, when the camera cannot be relied on.

**Placement.** Mounted on the perfboard at the top of the vehicle, in the detachable compute group. Mounting it on the deck fixes it rigidly to the chassis structure, which matters for an orientation sensor: compliance between the IMU and the wheels would appear as false motion in its output.

**Communication.** I²C, alongside the other bus devices.

**Datasheet:** [`adafruit-9-dof-orientation-imu-fusion-breakout-bno085.pdf`](./adafruit-9-dof-orientation-imu-fusion-breakout-bno085.pdf)

## MP1584 Voltage Regulator

<p align="center">
  
  
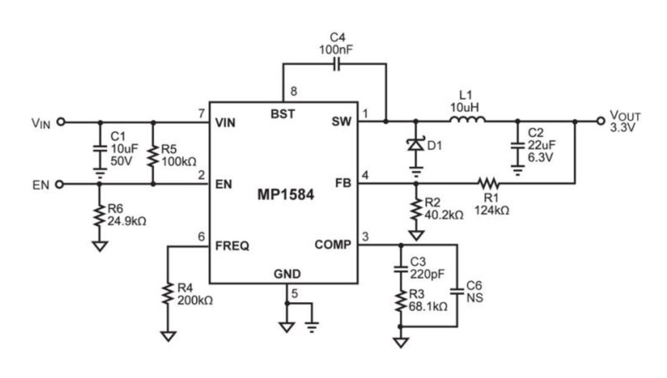
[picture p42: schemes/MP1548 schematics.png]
  
</p>
<p align="center">
  <em>MP1584 step down buck converter module and its reference schematic. The third file is stored in this folder as <code>MP1548 schematics.png</code>; the part is the MP1584.</em>
</p>

**Role.** The single voltage regulation stage in the vehicle. A high efficiency switching buck converter was selected in preference to a linear regulator such as an LM7805, because a linear part dissipates the voltage difference as heat. In a compact chassis that heat has nowhere to go, and the wasted energy shortens the usable time on a pack.

**Connections as drawn in the wiring schematic.**

| Pin | Function | Connection |
|---|---|---|
| `VIN+` | Input, positive | LiPo pack positive terminal |
| `VIN-` | Input, negative | Common ground |
| `Vout+` | Output, positive | Regulated logic rail |
| `Vout-` | Output, negative | Common ground |

**Supplied from this rail.** Raspberry Pi and Arduino Nano, the sensors, the motor driver's logic supply and the steering servo. The motor driver's motor supply does not pass through it and is taken from the pack directly.

**Datasheet:** [`MP1584EN-LF-Z.pdf`](./MP1584EN-LF-Z.pdf)

## TCA9548A I²C Multiplexer

<p align="center">
  
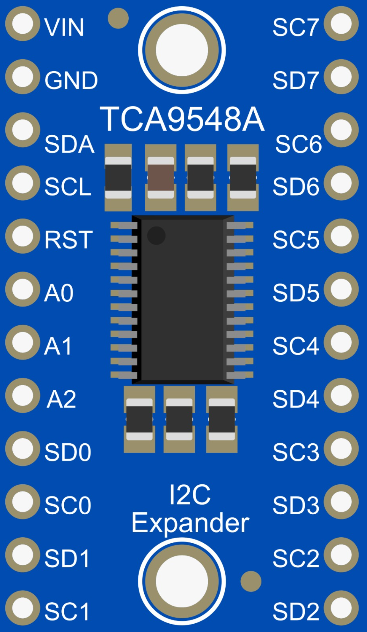
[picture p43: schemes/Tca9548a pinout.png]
  
</p>
<p align="center">
  <em>TCA9548A 8 channel I²C multiplexer and its pinout.</em>
</p>

**Role.** The ranging sensors are the reason this part is in the system. Identical I²C devices share an address, so several of them cannot sit on one bus without conflict. The multiplexer places each sensor on its own downstream channel, and the host selects a channel to address one sensor at a time. This keeps a single pair of I²C lines from the Raspberry Pi serving the whole sensor array.

**Connections as drawn in the wiring schematic.**

| Pin | Function | Connection |
|---|---|---|
| `VCC` | Supply | Logic rail |
| `GND` | Ground | Common ground |
| `SDA` | Upstream I²C data | Raspberry Pi `GPIO02/SDA1` |
| `SCL` | Upstream I²C clock | Raspberry Pi `GPIO03/SCL1` |
| `RST` | Reset | Control side |
| `A0`, `A1`, `A2` | Address select | Address configuration |
| `SD0`/`SC0` to `SD7`/`SC7` | Eight downstream channel pairs | One ranging sensor per channel |

**Placement.** Mounted in the compute group at the top of the vehicle, with the compute boards and the IMU.

**Datasheet:** [`TCA9548A.PDF`](./TCA9548A.PDF)

## Pinout and Schematic Reference

Quick navigation to the reference file for each component.

| Component | Pinout | Schematic | Datasheet |
|---|---|---|---|
| Raspberry Pi Zero 2 W | [`Raspberry pi zero W pinout.png`](./Raspberry%20pi%20zero%20W%20pinout.png) | [`PiZero-RAK-sch (1).png`](./PiZero-RAK-sch%20(1).png) | [`Raspberry pi 0 datasheet.pdf`](./Raspberry%20pi%200%20datasheet.pdf) |
| Raspberry Pi Camera | [`Raspberry pi camera pinout.png`](./Raspberry%20pi%20camera%20pinout.png) | [`Camera Module 3 reference schematic`](./RP-008969-SD-3-Raspberry%20Pi%20Camera%20Module%203%20Reference%20Schematic.pdf) | [`raspberry-pi-camera datasheet.pdf`](./raspberry-pi-camera%20datasheet.pdf) |
| Arduino Nano | [`A000005-full-pinout.pdf`](./A000005-full-pinout.pdf) | — | [`A000005-datasheet.pdf`](./A000005-datasheet.pdf) |
| VL53L1X | — | [`VL53LX-Distance-Sensor-Schematic.pdf`](./VL53LX-Distance-Sensor-Schematic.pdf) | [`VL53L1X.pdf`](./VL53L1X.pdf) |
| VL53L3CX | [`vl53l3cxdimensions.jpg`](./vl53l3cxdimensions.jpg) | [`VL53LX-Distance-Sensor-Schematic.pdf`](./VL53LX-Distance-Sensor-Schematic.pdf) | [`VL53L3CX.PDF`](./VL53L3CX.PDF) |
| BNO085 | [`BNO085 PINOUT.png`](./BNO085%20PINOUT.png) | — | [`adafruit BNO085 guide`](./adafruit-9-dof-orientation-imu-fusion-breakout-bno085.pdf) |
| TCA9548A | [`Tca9548a pinout.png`](./Tca9548a%20pinout.png) | — | [`TCA9548A.PDF`](./TCA9548A.PDF) |
| TB6612FNG | [`TB6612FNG..png`](./TB6612FNG..png) | — | [`TB6612FNG datasheet`](./TB6612FNG_datasheet_en_20121101.pdf) |
| MP1584 | — | [`MP1548 schematics.png`](./MP1548%20schematics.png) | [`MP1584EN-LF-Z.pdf`](./MP1584EN-LF-Z.pdf) |
| N20 motor | [`N20 encoder pinout`](./N20%20DC%20Gear%20Motor,%20Magnetic%20Hall%20Encoder,%20All-metal%20Gearbox%20pinout.png) | — | — |
| EMAX ES08MA II | [`Emax ES08MA II details.png`](./Emax%20ES08MA%20II%20%20details.png) | — | [`54-ES08MA.pdf`](./54-ES08MA.pdf) |
| Whole system | — | [`WIRING.pdf`](./WIRING.pdf) | [`Power System..pdf`](./Power%20System..pdf) |

## Datasheets

| Component | Datasheet | Description |
|---|---|---|
| Raspberry Pi Zero | [`Raspberry pi 0 datasheet.pdf`](./Raspberry%20pi%200%20datasheet.pdf) | Board specification for the main vision processor |
| Raspberry Pi Camera | [`raspberry-pi-camera datasheet.pdf`](./raspberry-pi-camera%20datasheet.pdf) | Camera module specification |
| Raspberry Pi Camera Module 3 | [`RP-008969-SD-3-Raspberry Pi Camera Module 3 Reference Schematic.pdf`](./RP-008969-SD-3-Raspberry%20Pi%20Camera%20Module%203%20Reference%20Schematic.pdf) | Manufacturer reference schematic |
| Arduino Nano | [`A000005-datasheet.pdf`](./A000005-datasheet.pdf) | Board specification for the real time controller |
| Arduino Nano pinout | [`A000005-full-pinout.pdf`](./A000005-full-pinout.pdf) | Full pin assignment reference |
| VL53L1X | [`VL53L1X.pdf`](./VL53L1X.pdf) | Long distance ToF ranging sensor, up to 400 cm, 27° full field of view |
| VL53L3CX | [`VL53L3CX.PDF`](./VL53L3CX.PDF) | ToF ranging sensor with multi target detection, 25° full field of view |
| VL53L series | [`VL53LX-Distance-Sensor-Schematic.pdf`](./VL53LX-Distance-Sensor-Schematic.pdf) | Distance sensor reference schematic |
| BNO085 | [`adafruit-9-dof-orientation-imu-fusion-breakout-bno085.pdf`](./adafruit-9-dof-orientation-imu-fusion-breakout-bno085.pdf) | 9 DoF orientation IMU with sensor fusion |
| TCA9548A | [`TCA9548A.PDF`](./TCA9548A.PDF) | 8 channel I²C multiplexer |
| TB6612FNG | [`TB6612FNG_datasheet_en_20121101.pdf`](./TB6612FNG_datasheet_en_20121101.pdf) | H-bridge motor driver |
| MP1584 | [`MP1584EN-LF-Z.pdf`](./MP1584EN-LF-Z.pdf) | Step down switching regulator |
| EMAX ES08MA II | [`54-ES08MA.pdf`](./54-ES08MA.pdf) | Metal gear micro servo |

No product links or prices are given. Components are identifiable from the names, images and datasheets above.

## Electrical Documentation Repository

Every file in this folder, organised by purpose.

### System documentation

| File | Contents |
|---|---|
| [`WIRING.pdf`](./WIRING.pdf) | Complete wiring schematic. Source of truth for all electrical connections. |
| [`Power System..pdf`](./Power%20System..pdf) | Power distribution architecture, rail assignments and consumption analysis. |
| [`Electrical_design_Philosophy.pdf`](./Electrical_design_Philosophy.pdf) | Electrical design philosophy: power architecture, noise isolation, sensor fusion strategy, communication and serviceability. |

### Component schematics and pinouts

| File | Contents |
|---|---|
| [`PiZero-RAK-sch (1).png`](./PiZero-RAK-sch%20(1).png) | Raspberry Pi Zero board reference schematic |
| [`Raspberry pi zero W pinout.png`](./Raspberry%20pi%20zero%20W%20pinout.png) | Raspberry Pi Zero GPIO pinout |
| [`Raspberry pi camera pinout.png`](./Raspberry%20pi%20camera%20pinout.png) | Camera connector pinout |
| [`A000005-full-pinout.pdf`](./A000005-full-pinout.pdf) | Arduino Nano full pinout |
| [`BNO085 PINOUT.png`](./BNO085%20PINOUT.png) | BNO085 breakout pinout |
| [`Tca9548a pinout.png`](./Tca9548a%20pinout.png) | TCA9548A pinout |
| [`TB6612FNG..png`](./TB6612FNG..png) | TB6612FNG reference |
| [`MP1548 schematics.png`](./MP1548%20schematics.png) | MP1584 reference schematic |
| [`mp1584.png`](./mp1584.png) | MP1584 reference |
| [`N20 encoder pinout`](./N20%20DC%20Gear%20Motor,%20Magnetic%20Hall%20Encoder,%20All-metal%20Gearbox%20pinout.png) | N20 motor and Hall encoder pinout |
| [`Emax ES08MA II  details.png`](./Emax%20ES08MA%20II%20%20details.png) | EMAX ES08MA II reference details |
| [`vl53l3cxdimensions.jpg`](./vl53l3cxdimensions.jpg) | VL53L3CX package dimensions |
| [`VL53LX-Distance-Sensor-Schematic.pdf`](./VL53LX-Distance-Sensor-Schematic.pdf) | VL53L series reference schematic |

### Component images

| File | Component |
|---|---|
| [`Raspberry Pi Zero.png`](./Raspberry%20Pi%20Zero.png) | Raspberry Pi Zero 2 W |
| [`Raspberry Pi Camera.png`](./Raspberry%20Pi%20Camera.png) | Raspberry Pi Camera |
| [`Arduino Nano.png`](./Arduino%20Nano.png) | Arduino Nano |
| [`VL53L1X ToF.png`](./VL53L1X%20ToF.png) | VL53L1X |
| [`VL53L3CX ToF.jpg`](./VL53L3CX%20ToF.jpg) | VL53L3CX |
| [`BNO085.jpg`](./BNO085.jpg) | BNO085 IMU |
| [`TB6612FNG.png`](./TB6612FNG.png) | TB6612FNG motor driver |
| [`MP1584 component.png`](./MP1584%20component.png) | MP1584 regulator |

Component photographs for the TCA9548A, N20 motor, servo and battery are held in the [`other`](../other/) folder.

## Technical Documentation

| Area | Documentation |
|---|---|
| Mechanical design and manufacturing files | [Models](../models/README.md) |
| Component references and research | [Other](../other/README.md) |
| Software implementation | [Source](../src/README.md) |
| Vehicle photographs | [Vehicle photos](../v-photos/README.md) |

*Team MadEngineerz, WRO 2026 Future Engineers*

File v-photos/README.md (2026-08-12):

# Vehicle Photos

This folder documents the MadEngineerz WRO 2026 Future Engineers robot from six orthographic views. The images are CAD renders of the complete assembly, and each view is annotated below with the components it makes visible.

## Photo List

### Front View — 

**Focus: forward sensing and front steering assembly**

* Raspberry Pi Camera mounted centrally on the front face of the upper structure
* Forward facing sensor module below the camera
* Front wheels and their steering pivots
* Steering linkage visible beneath the chassis, spanning both front knuckles
* Two part chassis with the upper frame lightening apertures and the lower section below

Front View

### Rear View — 

**Focus: rear axle and drivetrain**

* Rear drive axle spanning the full width of the vehicle
* Axle gear mounted on the shaft
* Rear wheels on the printed rims
* Lower section apertures around the drivetrain
* Upper frame with the electronics deck edge and connector visible along the top

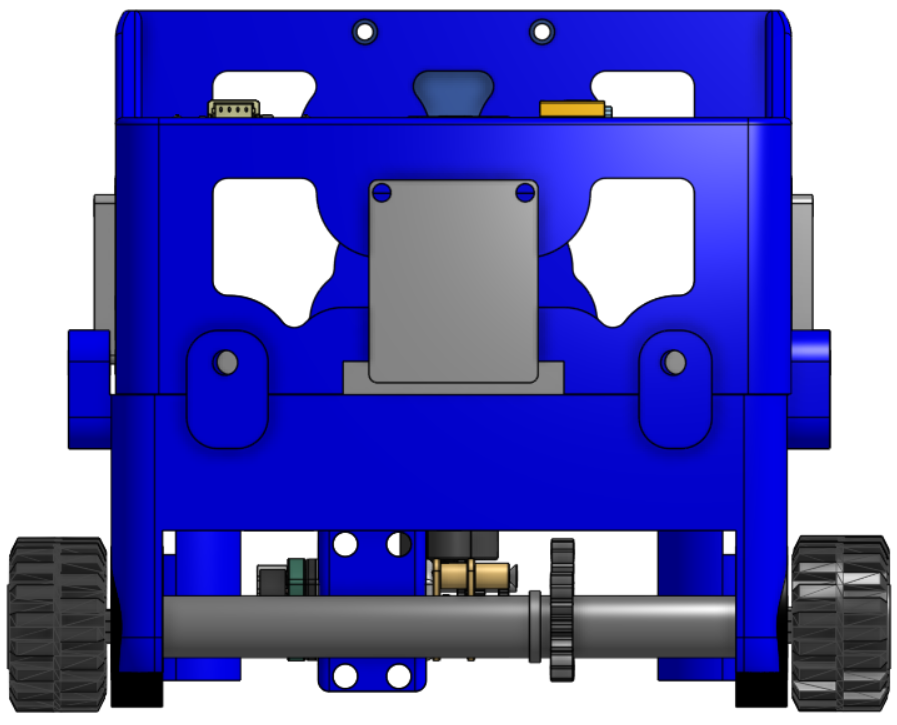
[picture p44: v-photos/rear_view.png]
Rear View


### Left View — 

**Focus: side profile and chassis architecture**

* Interface line between the upper and lower chassis sections, with the screw bosses that join them
* Lightening apertures in the upper frame
* Camera visible at the front edge of the vehicle
* Front and rear wheels showing the wheelbase
* Sensor module mounted low at the rear of the chassis

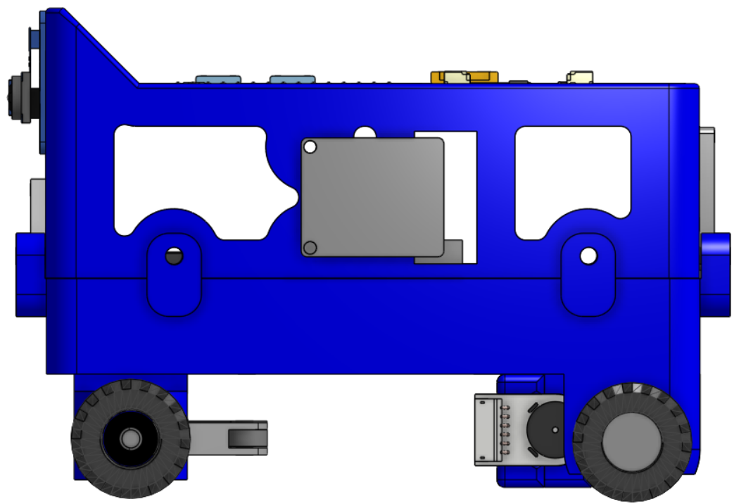
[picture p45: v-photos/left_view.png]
Left View


### Right View — 

**Focus: transmission and motor installation**

* N20 motor mounted at the rear of the lower section, with its encoder connector labelling visible
* Motor pinion engaging the drivetrain
* Interface between the upper and lower chassis sections
* Lightening apertures in the upper frame
* Camera visible at the front edge of the vehicle

Right View

### Top View — 

**Focus: electronics deck layout**

* Perfboard covering the upper section, forming the electronics platform
* Raspberry Pi Zero 2 W mounted centrally on the deck
* Arduino Nano at the rear of the deck
* LSM6DSOX IMU alongside the Nano
* All four wheels visible at the corners, showing the vehicle footprint

Top View

### Bottom View — 

**Focus: drivetrain and Ackermann steering mechanism**

* Rear drive axle with the spur gear pair, showing the motor pinion meshing with the axle gear
* N20 motor mounted transversely alongside the axle
* Steering servo with its horn driving the centre of the steering linkage
* Steering linkage connecting to both steering knuckles
* Steering knuckles pivoting in the chassis lugs at the front corners
* All four wheels, showing the track and wheelbase relationship

Bottom View

## Notes

These six views document the robot from every principal direction and are intended to show component placement and the layout of the mechanical, electrical and sensing systems. All images are CAD renders of the assembled vehicle.

## Technical Documentation

| Area | Documentation |
|---|---|
| Mechanical design and manufacturing files | [Models](../models/README.md) |
| Electrical design and schematics | [Schemes](../schemes/README.md) |
| Software implementation | [Source](../src/README.md) |
| Component references and research | [Other](../other/README.md) |

*Team MadEngineerz, WRO 2026 Future Engineers*

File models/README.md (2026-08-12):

# Mechanical Design — Models Documentation

**Team MadEngineerz · WRO 2026 Future Engineers**

This folder contains the manufacturing files and mechanical documentation for our autonomous vehicle. Every mechanical component in the robot was designed by the team in Onshape and manufactured in house on a Bambu Lab A1. This document explains not only what we built, but why each mechanical decision was made and what it delivers elsewhere in the design.

## Contents

* Mechanical Design Overview
* Design Philosophy
* Mechanical Specifications
* Chassis Architecture
* Ackermann Steering System
* Rear Wheel Drive and Spur Gear Transmission
* Transmission and Speed Analysis
* Mechanical Stability and Rigidity
* Design Iteration
* CAD and Manufacturing Workflow
* Why 3MF
* Complete Manufacturing File Repository
* Engineering Approach
* Validation
* Engineering Summary

## Mechanical Design Overview

<p align="center">
  
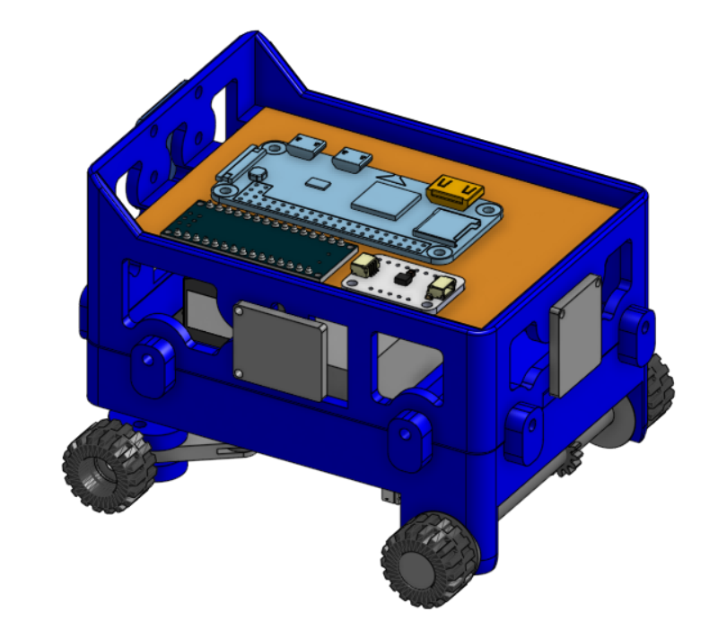
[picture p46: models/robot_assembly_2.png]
  
</p>
<p align="center">
  <em>Complete CAD assembly. The two part chassis carries all subsystems directly: the compute board and perfboard sit on the upper deck, the camera is mounted to the front structure, and the steering and drive hardware are packaged inside the lower section between the wheels.</em>
</p>

The vehicle is a four wheel car type platform with **Ackermann steering on the front axle** and **rear wheel drive through a spur gear pair**. This layout separates the steering function from the propulsion function, which keeps each mechanism simple enough to design, print and service as an independent subassembly.

<p align="center">
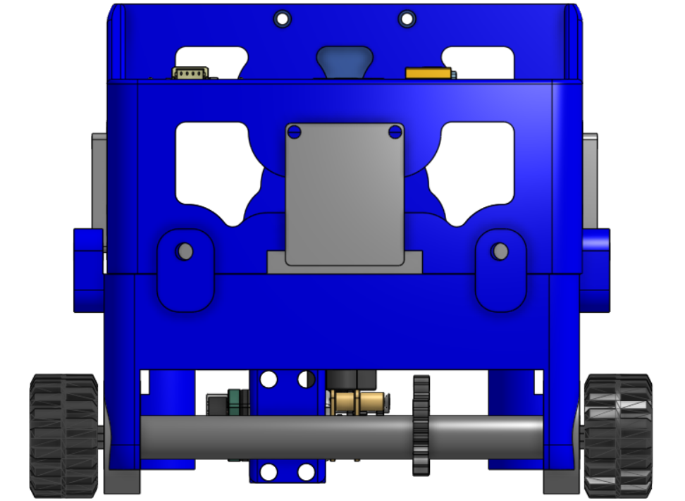
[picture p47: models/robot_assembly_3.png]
  
</p>
<p align="center">
  <em>Additional view of the complete assembly showing the packaging relationship between the drivetrain, steering hardware and the electronics deck.</em>
</p>

## Design Philosophy

Our mechanical design is built around **minimalism**: the smallest, lightest structure that still holds every component rigidly and in the right place. This is a deliberate engineering position rather than an aesthetic one, and it drove the following objectives.

| Objective | Why it matters mechanically |
|---|---|
| Keep the robot small | A shorter vehicle needs less clearance to complete a turn inside a fixed track width, and reduces the moment arm of any mass offset from the wheelbase. |
| Keep the robot lightweight | Lower mass means lower inertia to accelerate and decelerate, and lower load on every printed joint, bearing seat and gear tooth. |
| Maintain stability and rigidity | A structure that stays true under load keeps the wheels and camera in a fixed relationship, which preserves both steering accuracy and vision geometry. |
| Maintain optimal performance | Mechanical choices are made to serve the drive and steering behaviour, not the other way round. |
| Practical to assemble and maintain | Parts that can be removed and refitted quickly are parts that can be adjusted between runs at a competition. |

Every decision documented below traces back to one or more of these five objectives.

## Mechanical Specifications

| Parameter | Value |
|---|---|
| Length | 121 mm |
| Width | 83 mm |
| Height | 83 mm |
| Wheelbase | 67 mm |
| Front track | 85 mm |
| Mass, printed structure | 72.92 g |
| Steering | Ackermann geometry, front axle |
| Steering actuator | EMAX ES08MA II metal gear micro servo (×1) |
| Drive | Rear wheel drive, solid rear axle |
| Motor | N20 (GA12-N20) 6 V, 500 RPM output, with encoder |
| Transmission | Spur gear pair, 20 T motor to 15 T axle (4:3 step up) |
| Wheels | LEGO 87697, 21 mm outer diameter × 12 mm wide |
| Rear axle bearings | 626-2RS (×2) |
| Steering and front wheel bearings | 684-2RS (×2) |
| Fasteners | M2 screws throughout; nuts where required |
| Structural wall thickness | 3 mm, both chassis sections |
| Primary structural material | PLA |
| CAD | Onshape |
| Slicer and printer | Bambu Studio and Bambu Lab A1 |

### Printed part masses

| Part | Mass |
|---|---|
| Bottom part | 38.9 g |
| Top part | 26 g |
| Axle | 2.30 g |
| Motor mount | 1.19 g |
| Steering arm (left) | 0.8 g |
| Steering arm (right) | 0.8 g |
| Rear wheel rim (×2) | 1.4 g (0.7 g each) |
| Motor gear | 0.6 g |
| Steering linkage | 0.63 g |
| Axle gear | 0.30 g |
| **Total printed structure** | **72.92 g** |

The mass distribution across the printed structure is deliberate. The two chassis halves together account for **64.9 g of the 72.92 g total**, or roughly 89%, while the entire steering and drive hardware, meaning both steering arms, the linkage, both gears, the axle, the motor mount and both rims, comes to **8.02 g** combined. Within the chassis itself the split is also intentional: the lower section carries the drivetrain and steering loads and holds 38.9 g, while the upper section, which carries only the electronics deck, was reduced to 26 g by the lightening described in the iteration section.

This is the direct result of the minimalist approach. Mass sits in the load carrying structure where it earns stiffness, and almost none of it sits in the mechanisms that have to accelerate, rotate or swing, where mass would cost response instead.

## Chassis Architecture

<p align="center">
  
  
</p>
<p align="center">
  <em>Left: upper section, an open frame with large lateral and end apertures. Right: lower section, a tray with integrated paired lugs at each corner and moulded seats for the drivetrain. The two sections form a closed box when joined.</em>
</p>

### Two part construction

**Requirement:** the structure has to be stiff, but it also has to allow the electronics and drivetrain to be reached without dismantling the vehicle.

**Decision:** the chassis is split into an upper and a lower section, with extensions on the lower part forming the interface to the upper part. The two are joined with **8 M2 screws**.

**Engineering reason:** a single monolithic shell would either enclose the mechanism completely, making it unserviceable, or need large open faces that remove the very material providing the stiffness. Splitting the structure lets each half be a closed perimeter part in its own right, and the screwed joint between them recovers the stiffness at the seam. Eight fasteners distributed around the interface, rather than two or four, spread the clamping load and hold the sections square to each other.

**Implementation:** the lower section is a tray. Its walls and floor carry the drivetrain loads directly, and the paired lugs at each corner form the mounting points for the steering knuckles and the front wheel supports. The upper section is an open frame that carries the electronics deck. Because it does not carry drive or steering loads, its walls can be perforated with the large apertures visible above, removing material while preserving the load paths that matter. This aperture pattern was produced using the Lighten FeatureScript in Onshape, described in the iteration section below.

<p align="center">
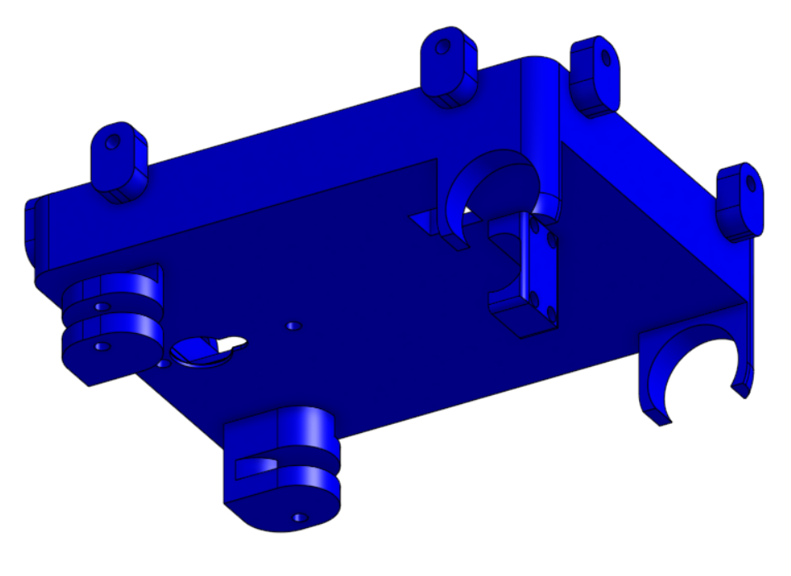
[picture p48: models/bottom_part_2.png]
  
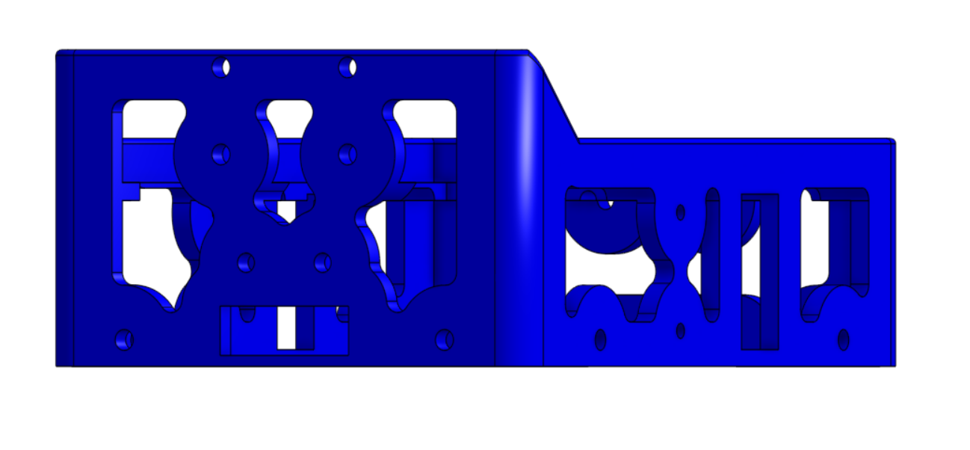
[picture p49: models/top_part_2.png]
  
</p>
<p align="center">
  <em>Alternate views of the two sections. The apertures in the upper frame are placed in regions that do not carry drivetrain or steering load; the closed perimeter rails around the top edge are retained to preserve torsional stiffness.</em>
</p>

### Direct component mounting

The camera and the remaining components are mounted directly to the printed structure rather than to intermediate brackets. Each mounting feature is dimensioned in CAD to the component it holds, so the component's own body becomes part of the assembly's dimensional chain.

Every intermediate bracket would add mass, add two more interfaces that can move, and add tolerance stack. For a camera in particular, any compliance between the sensor and the wheels changes the relationship between what the robot sees and where the robot actually is. Mounting the camera to the chassis structure itself keeps that relationship fixed.

### Electronics integration

The upper section provides a flat platform for the PCB and perfboard. Because the electronics sit on the top of the vehicle rather than inside it, wiring, probing and board changes can be done with the vehicle assembled. The deck is the outermost surface, not a buried one.

### Weight distribution

Component positions were adjusted iteratively in CAD until the weight distribution and the component layout were both satisfactory. Because the printed structure is only 72.92 g, the electronics and battery represent a significant fraction of the total vehicle mass, which makes where they sit a mechanical decision and not just a packaging one.

## Ackermann Steering System

<p align="center">
  
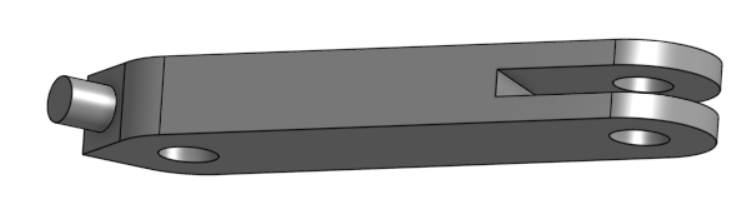
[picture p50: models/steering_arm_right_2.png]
  
</p>
<p align="center">
  <em>Mirrored left and right steering knuckles. Each has a clevis at the inboard end for the linkage, a stub axle carrying the front wheel bearing, and a through hole for the M2 kingpin screw that pivots it in the chassis lug.</em>
</p>

### The principle

When a vehicle turns, the inner and outer front wheels travel on circles of different radii about the same instantaneous centre. If both wheels are steered to the same angle, at least one of them must point away from the direction it is actually travelling, and the difference is absorbed as **tyre scrub**, where the wheel slides sideways as it rolls.

Ackermann geometry addresses this by steering the inner wheel through a larger angle than the outer wheel, so that a perpendicular drawn from each front wheel meets a perpendicular from the rear axle at a single common centre. Both front wheels then roll along their own true paths instead of being dragged across them. The geometry is realised by angling each steering arm inboard so that the arms project toward the centre of the rear axle, which makes the correct angular relationship an inherent property of the linkage rather than something the control system has to correct for.

### Why Ackermann was selected

**Requirement:** the vehicle must follow a consistent, repeatable path, because the navigation software infers position partly from commanded steering.

**Decision:** Ackermann geometry rather than a parallel or simplified steering arrangement.

**Engineering reason:** reduced tyre scrub during cornering produces smoother turns, better stability and more consistent path tracking. Scrub is not only a friction loss, it is a source of variability, because the amount of sideways slip changes with surface, load and speed. Designing it out makes the relationship between commanded steering angle and actual path more repeatable, which is exactly what an autonomous vehicle depends on.

### Linkage and actuation

<p align="center">
  
</p>
<p align="center">
  <em>Steering linkage. The two outer holes connect to the clevis on each steering knuckle; the centre hole is driven by the servo, so a single actuator displaces both knuckles simultaneously through the Ackermann geometry.</em>
</p>

The linkage was designed to **minimise mechanical play while remaining easy to assemble, adjust and replace**. Play in a steering linkage is cumulative, since clearance at each joint adds up at the wheel and appears as a dead band in which servo commands produce no wheel movement. Keeping the joint count low and the fits tight is the mechanical countermeasure, and it is why the linkage is a single part driving both knuckles rather than a multi part assembly.

The knuckles pivot on **M2 screws** acting as kingpins in the paired chassis lugs. Using a screw rather than a printed pin means the pivot surface is metal, the fit can be adjusted by tightening, and a worn joint can be restored by replacing a fastener rather than reprinting a structural part.

Each front wheel runs on a **684-2RS sealed bearing** on the knuckle stub axle. A sealed ball bearing at the wheel keeps rolling resistance low and, more importantly for steering accuracy, locates the wheel radially with a precision that a printed plain bore would not hold as it wears.

### Actuator selection

Steering is actuated by a single **EMAX ES08MA II metal gear micro servo**, selected for its compact size, low mass, metal gear train, adequate torque and precise positioning. The metal gear train is the decisive point for a steering application: the linkage transmits impact loads back into the actuator whenever a wheel meets an obstruction, and metal gears keep the actuator intact under exactly the condition that would otherwise end a run. Its compact envelope also allows the servo to sit low inside the lower chassis section, which keeps its mass close to the floor of the vehicle.

## Rear Wheel Drive and Spur Gear Transmission

<p align="center">
  
  
</p>
<p align="center">
  <em>The transmission pair. Left: 20 tooth motor pinion on the N20 D shaft. Right: 15 tooth axle gear with a bore sized to the drive axle. The larger gear drives the smaller, producing a step up in wheel speed.</em>
</p>

### Why rear wheel drive

**Requirement:** a compact drivetrain that does not interfere with the steering mechanism.

**Decision:** rear wheel drive with a single motor on a solid rear axle.

**Engineering reason:** rear wheel drive **separates steering from propulsion**. On a front wheel drive layout, the driven wheels must also pivot, so the drive path has to accommodate a steering angle. That requires either flexible couplings or constant velocity joints, both of which are demanding to produce at this scale by FDM printing and both of which introduce play into the steering. Driving the rear axle lets the drive path be a single straight shaft and lets the front axle be a pure steering mechanism. Each subsystem then does one job, which is what makes both of them simple enough to print reliably.

### Drive path

<p align="center">
  
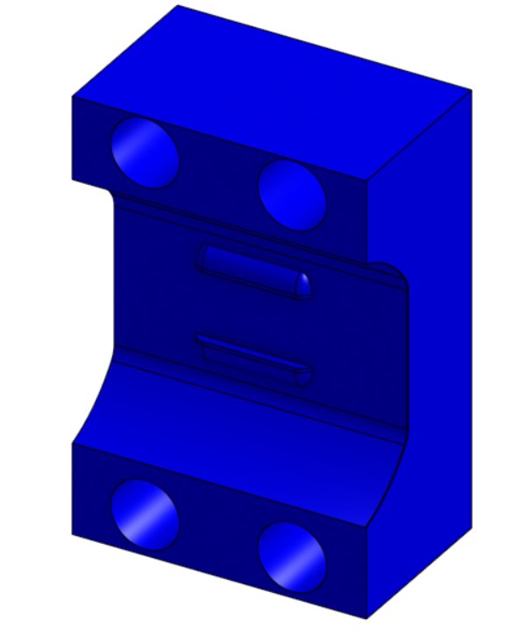
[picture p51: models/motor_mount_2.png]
  
</p>
<p align="center">
  <em>Left: rear drive axle, with cross profile ends that engage the wheel rims and transmit torque by positive form lock rather than friction. Right: motor mount, which fixes the N20 body to the chassis and sets the centre distance between the motor pinion and the axle gear.</em>
</p>

Power flows from the motor to the 20 T pinion, into the 15 T axle gear, along the rear axle, through the rim and into the LEGO wheel.

<p align="center">
  
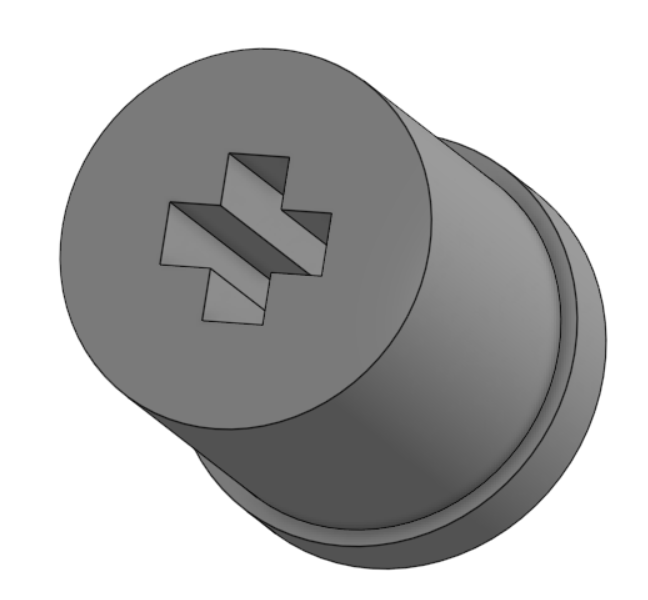
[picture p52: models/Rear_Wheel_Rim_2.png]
  
</p>
<p align="center">
  <em>Rear wheel rim. The cross shaped socket mates with the axle end, so drive torque is carried by the profile itself rather than by a friction fit.</em>
</p>

The axle is supported by **two 626-2RS sealed bearings** in the lower chassis section. Two widely spaced bearings, rather than a single bearing or a pair of printed plain bores, constrain the axle in two planes and hold it square under the side load that the gear mesh applies. This keeps the gear centre distance constant while the drive is loaded, which is what keeps the mesh consistent.

The motor mount is the part that establishes the **centre distance between the two gears**. This is the most sensitive dimension in the transmission, since too close and the teeth bind, too far and the mesh loses contact ratio. Making the mount a discrete part rather than a feature of the chassis means this dimension can be adjusted and reprinted at a cost of 1.19 g, without touching the 38.9 g chassis.

### Why spur gears

**Decision:** a plain spur gear pair, chosen over helical and double helical alternatives that were also modelled during development.

**Engineering reason:** a spur pair transmits torque between parallel shafts with no axial thrust component. Helical teeth generate an axial force that must be reacted somewhere, and in a design where the axle is located by two bearings and everything else is printed plastic, that means designing for an additional load path. The spur pair also puts the entire tooth profile in a single print layer plane, which is the geometry FDM reproduces most faithfully at this tooth size.

Using a discrete gear pair rather than a fixed reduction also means **the ratio itself is a design variable**. Changing the drive characteristics costs one reprint of a 0.6 g and a 0.3 g part, which is what made it practical to evaluate several tooth combinations during development.

## Transmission and Speed Analysis

### Transmission ratio

The 20 tooth pinion on the motor drives the 15 tooth gear on the axle. The larger gear drives the smaller, so this is a **step up**:

```
i = N_driver / N_driven = 20 / 15 = 1.333   (4:3)
```

### Wheel speed

```
n_wheel = n_motor × i
        = 500 RPM × 1.333
        = 666.7 RPM
```

### Linear speed

With LEGO 87697 wheels of 21 mm outer diameter:

```
C = π × D = π × 0.021 m = 0.0660 m per wheel revolution

v = C × (n_wheel / 60)
  = 0.0660 × (666.7 / 60)
  = 0.73 m/s
```

This is a **theoretical figure**, calculated from the motor's rated output speed, the gear tooth counts and the wheel diameter.

### Encoder feedback

The N20 unit includes a quadrature encoder rated at 3 pulses per revolution. Because the encoder reads at the motor and the wheel is coupled through a fixed 4:3 ratio and a positive form lock at the rim, motor rotation maps deterministically to wheel rotation. There is no belt or friction coupling anywhere in the path that could slip and break that relationship, and this determinism is a mechanical property of the drivetrain that the control system relies on.

## Mechanical Stability and Rigidity

Rigidity is pursued here for a specific reason: every millimetre of unwanted movement in the structure would become an error in the steering and vision systems. The measures below are the ones taken to prevent it.

| Measure | Mechanical effect |
|---|---|
| 3 mm walls on both chassis sections | Bending stiffness of a wall in this configuration rises steeply with thickness. 3 mm holds the structure well clear of being the compliant element in the assembly. |
| Closed box two part architecture | Joining an open tray to an open frame produces a closed section, which is far stiffer in torsion than either half alone. Torsional stiffness is what keeps all four wheels loaded on an uneven surface. |
| 8 M2 screws at the chassis interface | Distributed clamping holds the two halves square to each other and turns the seam into a load carrying joint. |
| Two 626-2RS bearings on the rear axle | Constrain the axle against the side load from the gear mesh, holding the gear centre distance constant under drive load. |
| 684-2RS bearings at the front wheels | Locate each front wheel radially with a precision that is maintained over the life of the assembly. |
| M2 screws as steering kingpins | Metal pivot surfaces, adjustable by tightening, replaceable without reprinting structure. |
| Direct component mounting | Removes intermediate brackets along with the tolerance stack and compliance each one would add. |
| Low structural mass | Lower mass means lower inertial loads into every joint during acceleration, braking and cornering. Rigidity and lightness reinforce each other in this design rather than competing. |
| Apertures placed off the load paths | Material is removed from the upper frame, which carries no drivetrain or steering load, and retained in the lower tray, which carries both. The lightening pattern leaves the closed perimeter rails intact so the frame retains its torsional stiffness. |

## Design Iteration

The design reached its current form through two phases of iteration. The first was on paper, where a large number of design sketches were used to explore vehicle layouts, subsystem arrangements and component packaging before modelling began. The second was in CAD, where the alternatives below were modelled, evaluated and refined against one another. The table records what was tried and what was adopted.

| # | Subsystem | Alternatives evaluated | Outcome |
|---|---|---|---|
| 1 | Transmission ratio | Multiple tooth count combinations modelled | 20 T motor and 15 T axle (4:3) adopted |
| 2 | Gear type | Helical and double helical gears modelled | Plain spur gear pair adopted |
| 3 | Wall thickness | 4 mm walls | Refined to 3 mm |
| 4 | Chassis architecture | Single piece chassis | Split into two sections |
| 5 | Rear drive | Mechanical differential considered | Spur gear drive on a solid axle adopted |
| 6 | Upper section mass | Solid upper frame | Lightened using the Lighten FeatureScript in Onshape |
| 7 | Component layout | Multiple component positions | Final layout fixed once weight distribution and packaging were satisfactory |

### Notes on the significant decisions

**Transmission ratio.** Several tooth count combinations were modelled before the 20 T and 15 T pair was adopted. Because both gears are small printed parts, evaluating a ratio was inexpensive, which allowed the choice to be made by comparison across options rather than by picking one at the outset.

**Gear type.** Helical and double helical gearing offers smoother engagement and higher contact ratio in conventional machine design, and both forms were modelled before the plain spur pair was adopted. The mechanical properties that favour a spur pair in this application, namely the absence of axial thrust to react into printed structure and a tooth profile that lies in the print plane, are set out in the transmission section above.

**Wall thickness.** The chassis was first modelled with 4 mm walls and refined to 3 mm. The chassis sections dominate the structural mass at 64.9 g of the 72.92 g total, so wall thickness is the single largest lever on vehicle mass, acting on the two largest parts in the vehicle. The 3 mm result retains the stiffness the structure needs while removing mass where there was most of it to remove.

**Chassis architecture.** The chassis began as a single piece and was split into upper and lower sections after design trade off analysis. The resulting architecture is what provides the serviceability and electronics access described earlier, and the screwed interface between the halves is what preserves rigidity across the split.

**Rear drive.** A mechanical differential was considered for the rear axle, and the spur gear drive on a solid axle was adopted instead. The consequence is accepted knowingly: with a solid axle, both rear wheels turn at the same speed, so during a turn the rear wheels share a single rotational speed between them. At 72.92 g the resulting forces are small, while a printed differential would have added several additional gears, bearing surfaces and a housing to the one subsystem that transmits continuous load. Part count and reliability were traded against differential action, and reduced tyre scrub is delivered at the front axle by the Ackermann geometry, where the steering angles make it matter most.

**Upper section lightening.** The upper section was lightened using the **Lighten FeatureScript in Onshape**, which generates a lightening pattern through the part rather than requiring each pocket to be sketched individually. Applying it to the upper frame removed mass from the section that carries no drivetrain or steering load, while leaving the closed perimeter rails and the surrounding material that provide the frame's stiffness. This is the origin of the aperture pattern visible in the upper section renders, and it is why the upper frame can be lightened aggressively without weakening the structure.

**Component layout.** Component positions were moved repeatedly through CAD iterations until both the weight distribution and the component packaging were satisfactory. Because the chassis holds every component directly, moving a component means moving its mounting features, so layout and structure were refined together rather than in sequence.

## CAD and Manufacturing Workflow

All parts were designed in **Onshape**, a browser based parametric CAD platform. The practical advantages for a student team are that the model is version controlled and accessible to every member without local installation or file synchronisation, which matters when several people iterate on interlocking parts.

Because Onshape is parametric, the dimensional interfaces that hold the design together, including the gear centre distance in the motor mount, the bearing seats, the kingpin lug spacing and the screw pattern between the two chassis halves, are defined as driven dimensions rather than sketched by eye. Changing one propagates through the affected geometry, which is what made the iteration described above practical to carry out.

```
Onshape  →  CAD Design  →  Manufacturing Preparation  →  Bambu Studio  →  3D Printing  →  Assembly  →  Testing
```

| Stage | Tool or method |
|---|---|
| CAD design | Onshape |
| Manufacturing preparation | Part orientation and print arrangement |
| Slicing | Bambu Studio |
| Printing | Bambu Lab A1 |
| Assembly | M2 screws, with nuts where required |

### Material selection

**PLA** is used for the main structure. For a vehicle of this mass the loads in the chassis are low, and PLA offers the highest stiffness of the common FDM materials along with excellent dimensional accuracy, which is the property that actually governs this design: the bearing seats, gear bores and screw interfaces all depend on printed dimensions landing within tolerance. A tougher but less dimensionally stable material would trade away the precision the mechanism relies on in exchange for impact resistance that a vehicle of this mass does not call for.

The **wheels are LEGO 87697** at 21 mm diameter by 12 mm wide. Injection moulded rubber tyres offer consistent, repeatable traction and dimensional uniformity between units, and using a standard component means a worn wheel is replaced identically. The printed rim is the adapter between that standard component and our axle.

Print settings for the top part use the **Bambu Studio default profile**.

## Why 3MF

Manufacturing files in this folder are supplied in **3MF** rather than STL or vendor G code.

* **Broad compatibility.** 3MF is an open format read by all major slicers, so the files are not tied to one toolchain the way a printer specific G code file would be.
* **Print information is preserved.** Unlike STL, which carries only triangle geometry, a 3MF retains the print configuration alongside the model.
* **Orientation and arrangement are preserved.** The way each part is positioned and rotated on the build plate is carried in the file. Orientation is a genuine engineering decision on these parts, since it determines the direction of the layer lines relative to the loads and to the printed bores, so preserving it preserves part of the design intent.
* **Manufacturing settings are supported.** Per object settings and modifications survive the transfer rather than needing to be reapplied by hand.
* **Reproducibility.** Another team opening these files starts from our configuration rather than reconstructing it.
* **Simpler handoff into the slicing workflow.** The file opens directly into a prepared plate.

3MF does not guarantee identical output on every printer. Nozzle diameter, extrusion system, motion characteristics, calibration state and filament all vary between machines, and printer specific settings may need adjustment. What 3MF preserves is our configuration and intent as the starting point.

We publish 3MF deliberately rather than native CAD source. The intent is that another team can **manufacture this robot exactly as we designed it**, while the design itself remains our own work.
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

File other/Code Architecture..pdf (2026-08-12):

# Code Architecture

## Obstacle Challenge

For the Obstacle Challenge, the robot will primarily rely on the camera for navigation, with the other sensors serving specific supporting roles.

Sensor Reliance

Sensor | Approx.
Reliance

Primary Purpose

Raspberry Pi Camera 75% | Obstacle detection, colour identification,
navigation
TOF Sensors | 5% | Parking, crash prevention, and final positioning
IMU + Rotary Encoder Supporting | Parking guidance and path mapping

The TOF sensors will have the highest authority when detecting an immediate risk of collision. The IMU and rotary encoder may also be used after the first round to plot a stable path for the following two rounds.

# Code Structure

## Camera Computation & Processing:

The manner in which we process frames yielded by the camera is imperative to the functioning of our creation. Due to severe, unforeseen hardware limitations created due to the unavailability of the successor of the raspberry pi zero w, which would’ve provided us with a 64 bit multi-core processor with 5 times the processing power, we have been forced to optimise our computation process as much as possible to the extent of our ability, regardless if readability is compromised or not. The overall structure of our processing is as follows:

After initialization of the camera:
1. Raw 422 camera data is immediately captured in a “While (True)” loop at QQVGA, or 160x120 px.
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

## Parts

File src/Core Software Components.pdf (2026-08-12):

## Core Software Components

- Primary Processing Languages:
- Python 3: Deployed on the Raspberry Pi for high-level tasks including image processing, sensor integration, state management, and steering calculation.
- C++ (Embedded): Deployed on the Arduino Nano for deterministic, real-time control of motor PWM and servo steering commands.
- Core Libraries & Dependencies:
- Raspberry Pi Environment: Picamera2 / libcamera (high-frame-rate hardware camera pipeline), OpenCV & NumPy (vectorized color extraction and spatial matrix math), pyserial (inter-board communication), time.
- Arduino Environment: Built-in hardware Serial interface, custom low-level motor driver logic.
- Functional Task Distribution:

+-----------------------------------------------------------------------------------+

| | RASPBERRY PI | |
| - High-Frame-Rate Video Pipeline | - Vision-Based Target & Line Identification|

| - Time-of-Flight (ToF) Distance Array - High-Level Navigation & State Machine |

| - Rotary Encoder Odometry Tracking - Steering PID Math Calculation |

+-----------------------------------------+-----------------------------------------+

| | UART (ASCII String Messages)
| v

+-----------------------------------------------------------------------------------+

| | ARDUINO NANO | |
| - Servo Steering Angle Execution | - DC Motor Direction & PWM Speed Control |

+-----------------------------------------------------------------------------------+

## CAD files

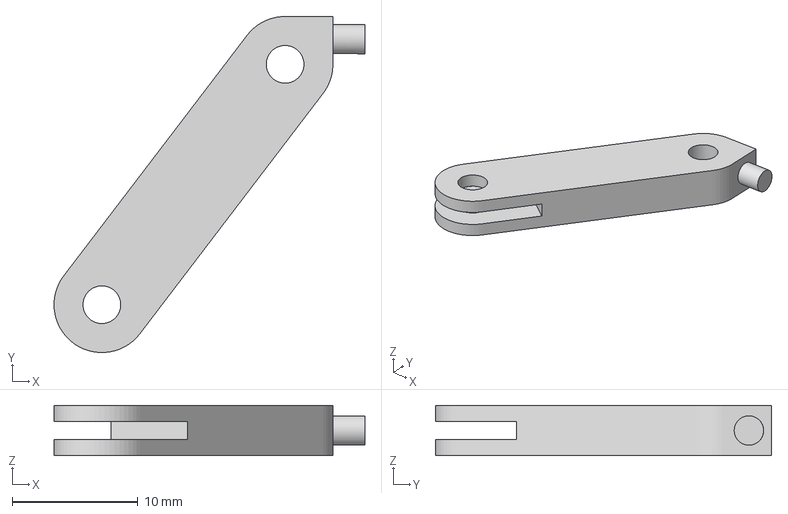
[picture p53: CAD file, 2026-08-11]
models/steering_arm_left.3mf
24.8 x 26.8 x 4.00 mm

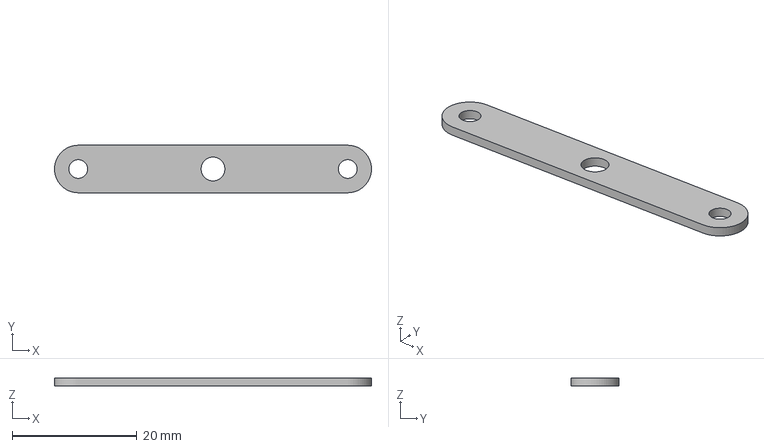
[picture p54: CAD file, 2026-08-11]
models/steering_linkage.3mf
50.8 x 7.62 x 1.30 mm

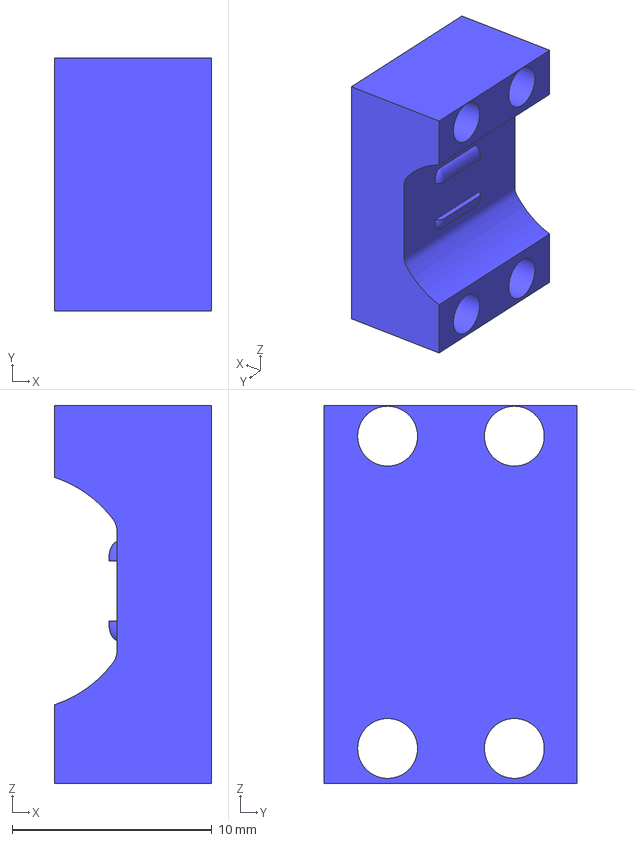
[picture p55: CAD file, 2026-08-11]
models/Motor mount.3mf
7.87 x 12.7 x 18.9 mm

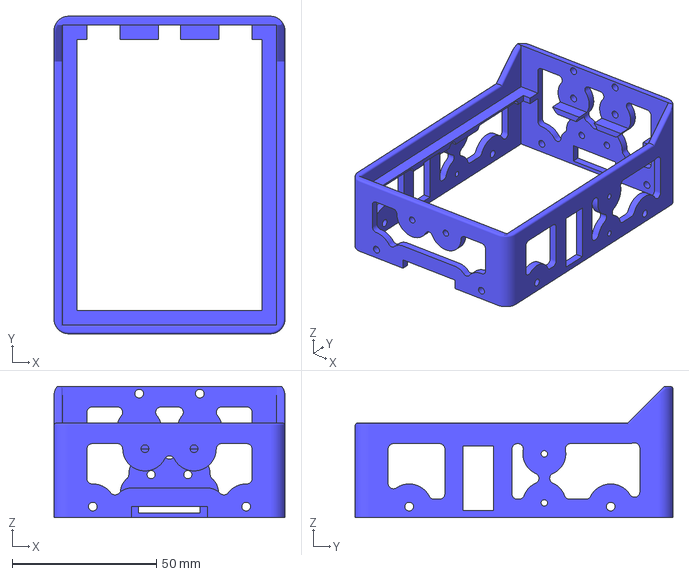
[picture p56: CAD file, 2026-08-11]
models/Top Part.3mf
80.0 x 110.0 x 45.4 mm

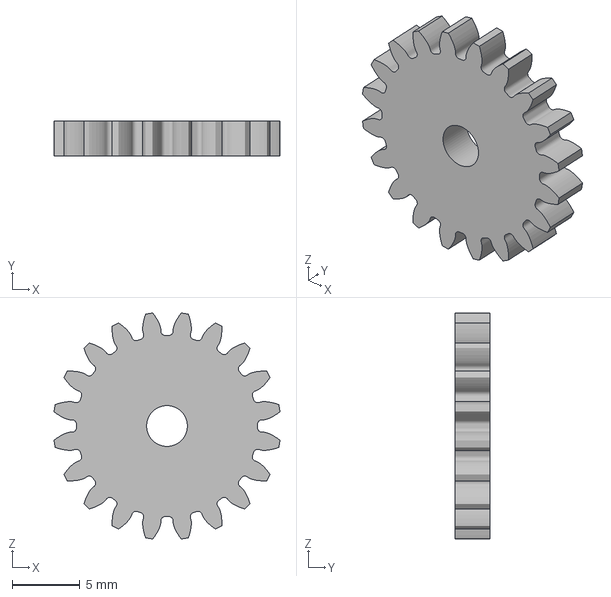
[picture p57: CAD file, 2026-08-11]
models/Motor Gear.3mf
16.6 x 2.54 x 16.6 mm

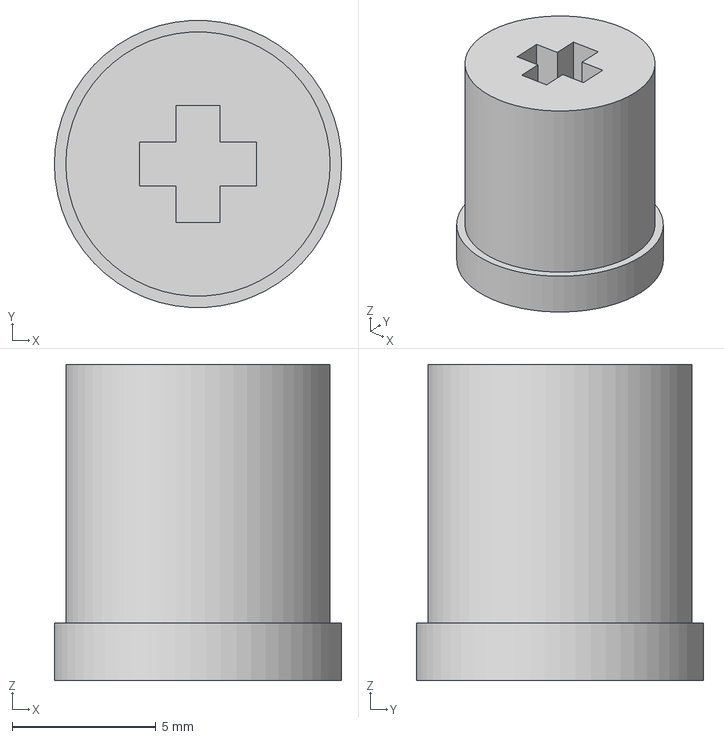
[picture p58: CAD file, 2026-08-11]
models/Rear wheel rim.3mf
10.0 x 9.99 x 11.0 mm

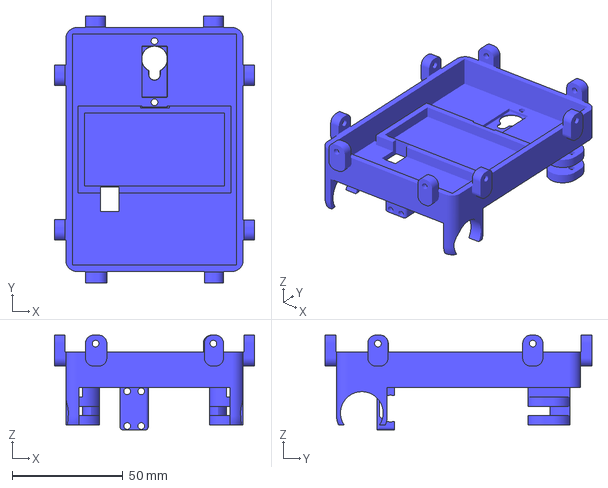
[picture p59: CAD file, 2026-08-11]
models/Bottom part.3mf
90.2 x 120.2 x 42.7 mm

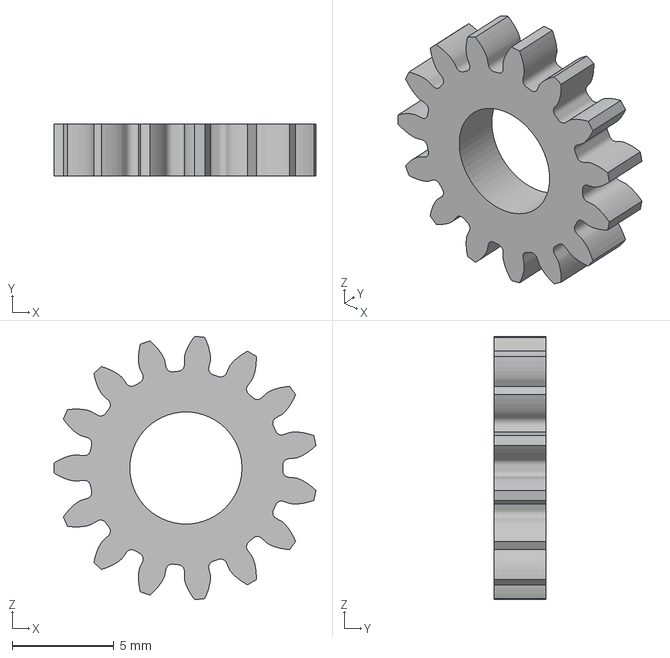
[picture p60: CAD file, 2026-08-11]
models/Axle gear.3mf
12.9 x 2.54 x 12.9 mm

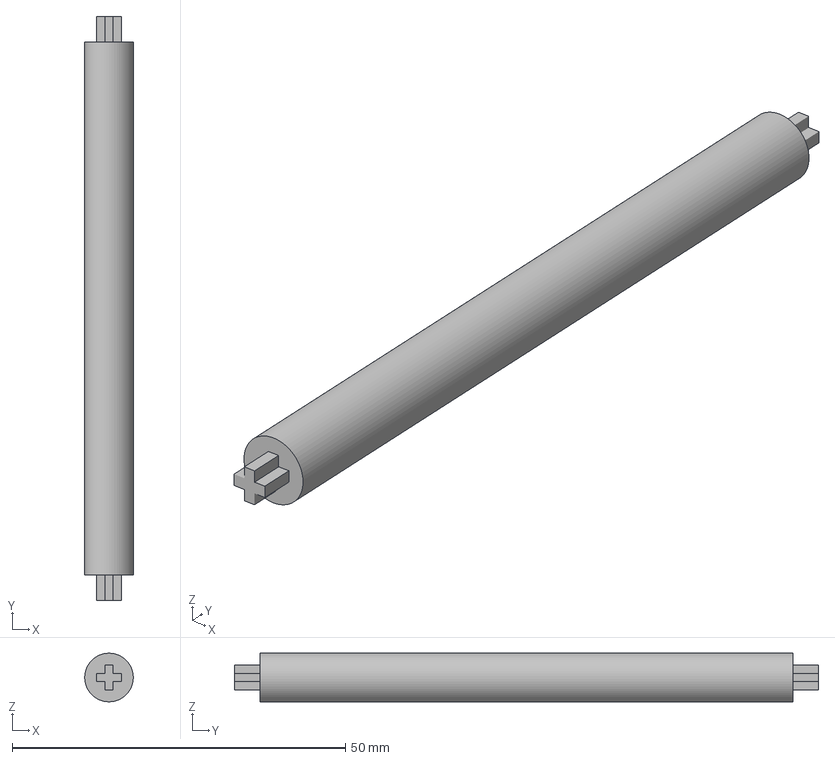
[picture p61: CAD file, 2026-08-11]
models/Axle.3mf
7.29 x 87.6 x 7.30 mm

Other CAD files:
models/steering_arm_right.3mf

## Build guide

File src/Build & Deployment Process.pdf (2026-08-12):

## Build & Deployment Process

- Development & Deployment Interface: Code deployment to the main computing unit (Raspberry Pi) is executed over SSH via direct Ethernet or a dedicated Wi-Fi hotspot. This setup ensures low-latency remote terminal management and rapid code iteration during pit debugging without requiring external monitors.
- Microcontroller Flashing: Embedded real-time firmware for the Arduino Nano is compiled and flashed using the standard Arduino IDE framework over a direct USB serial link.
- Status Verification & Startup Diagnostics: To remain fully compliant with competition hardware restrictions regarding external discrete LEDs, system boot and script execution are indicated using the Raspberry Pi’s onboard green status LED (ACT LED) mapped via GPIO triggers.

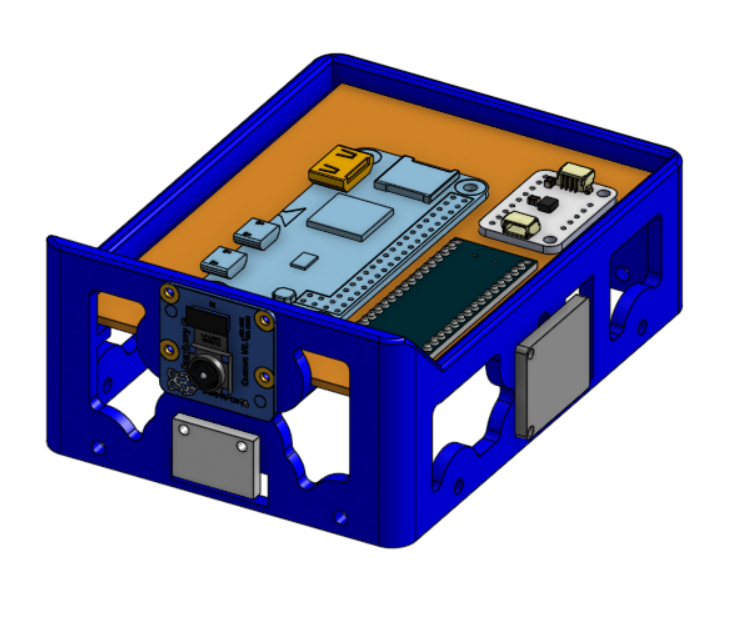
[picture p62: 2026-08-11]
models/Top_Part_Assembly.png

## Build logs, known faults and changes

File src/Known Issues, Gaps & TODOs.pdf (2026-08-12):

## Known Issues, Gaps & TODOs

Critical Hardware & Baud Conflicts

- Pin Allocation Conflict: Both Servo.cpp and MotorPWM.cpp currently attempt to use Pin 9.
- Baud Rate Mismatch: Standalone C++ test files open serial at 9600 baud, while Nanotransmissionreceiver.cpp operates at 115200 baud.

Open Development Items

- Integration: Re-enable and wire the commented-out actuator hardware calls in Nanotransmissionreceiver.cpp to the servo and motor routines.
- PID System: Write the standalone PID steering loop and reference angle calculation modules.
- Color Bounds: Replace temporary inline U/V test bounds with dedicated Red and Green calibration sets.
- Transmission Delay: Tune the time.sleep(0.1) transmission loop delay against real-time camera FPS.
- Code Cleanup: Remove test scaffolding (input() calls in Python, terminal prints in vision module, test print statements).
- Optimization: Evaluate dropping center_y calculation if unneeded by the PID avoidance algorithm.

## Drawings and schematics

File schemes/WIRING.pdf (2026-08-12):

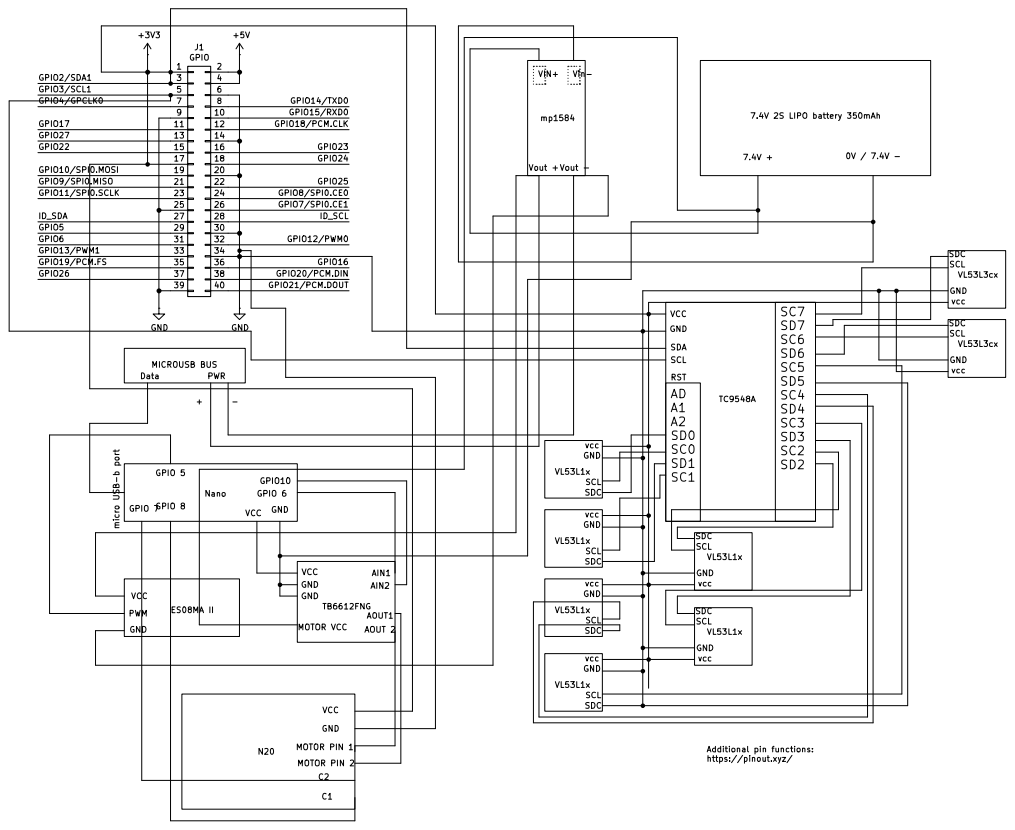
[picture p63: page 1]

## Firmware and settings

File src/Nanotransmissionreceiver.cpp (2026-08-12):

#include <Arduino.h>

// 1. Global Variables to store parsed command parameters
int servoAngle = 90; // Default center position
int motorSpeed = 0;  // Default stopped position

// 2. State management variables for reading the stream
String inputBuffer = "";
unsigned long lastPacketTime = 0;
const unsigned long TIMEOUT_MS = 200; // 200ms Failsafe threshold

void setup() {
  // Initialize USB Serial interface at the identical baud rate set on the Pi
  Serial.begin(115200); 
  
  // Set lower execution allowance for stream strings to prevent loop drag
  Serial.setTimeout(2); 

  pinMode(LED_BUILTIN, OUTPUT);
}

void loop() {
  // 3. Asynchronous Cache Reading Loop
  while (Serial.available() > 0) {
    char incomingChar = (char)Serial.read();
    
    // Check if character marks the end of a transmission payload
    if (incomingChar == '\n') {
      parseControlString(inputBuffer);
      inputBuffer = ""; // Reset cache immediately for next string package
    } else {
      inputBuffer += incomingChar; // Cache character pieces dynamically
    }
  }

  // 4. Critical Hardware Safety Watchdog Checks
  if (millis() - lastPacketTime > TIMEOUT_MS) {
    motorSpeed = 0; // Cut drive motor throttle instantly
    digitalWrite(LED_BUILTIN, HIGH); // Visual warning indicator active
  } else {
    digitalWrite(LED_BUILTIN, LOW);
  }

  // --- ACTUATOR RUN ROUTINE GOES HERE ---
  // analogWrite(motorPin, abs(motorSpeed));
  // steeringServo.write(servoAngle);
}

// 5. String Processing and Unpacking Engine
void parseControlString(String data) {
  // Validate presence of starting packet header index marker '$'
  if (data.startsWith("$")) {
    data.remove(0, 1); // Strip header '$' away cleanly
    
    int commaIndex = data.indexOf(',');
    if (commaIndex != -1) {
      // Isolate components relative to delimiter positioning
      String steerString = data.substring(0, commaIndex);
      String speedString = data.substring(commaIndex + 1);
      
      // Update running variable values natively
      servoAngle = steerString.toInt();
      motorSpeed = speedString.toInt();
      
      lastPacketTime = millis(); // Refresh active loop timeline state check
      Serial.println("OK"); 
    }
  }
}

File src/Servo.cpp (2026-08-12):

#include <Servo.h>

// Instantiate the Servo object (similar to Python's class instantiation)
Servo myServo;

// Define the hardware control pin
const int SERVO_PIN = 9;

void setup() {
  // Initialize serial communication for debugging at 9600 baud
  Serial.begin(9600);
  
  // Attach the servo and unlock the extended 600µs to 2400µs pulse limits
  // This maps 0 degrees to 600µs and 180 degrees to 2400µs
  myServo.attach(SERVO_PIN, 600, 2400);
  
  Serial.println("Servo initialized with extended range (600us - 2400us).");
}

void loop() {
  // Sweep to 0 degrees (Generates a 600µs pulse width)
  Serial.println("Moving to 0 degrees...");
  myServo.write(0);
  delay(2000); // Wait 2 seconds for mechanical travel
  // Sweep to 90 degrees (Generates a 1500µs pulse width - Center)
  Serial.println("Moving to 90 degrees...");
  myServo.write(90);
  delay(2000);

  // Sweep to 180 degrees (Generates a 2400µs pulse width)
  Serial.println("Moving to 180 degrees...");
  myServo.write(180);
  delay(2000);
}

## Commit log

2026-08-12 Revise battery placement section in README
    Updated the link text for the battery plan document and clarified its content regarding battery placement and weight distribution.
2026-08-12 Enhance clarity in concept development section
    Revised the description of the concept development stage to improve clarity and detail.
2026-08-12 Replace LSM6DSOX IMU with BNO085 IMU in README
2026-08-12 Update image extension for BNO085 IMU in README
2026-08-12 Add electrical documentation for WRO 2026 robot
    Added comprehensive electrical documentation for the MadEngineerz WRO 2026 robot, including wiring schematics, power management, and component details.
2026-08-12 Add detailed software documentation for robot system
    Added comprehensive documentation for the software architecture and components of the MadEngineerz WRO 2026 robot, detailing the roles of Raspberry Pi and Arduino Nano, programming environment, core 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
2026-08-12 Revise code architecture research details in README
    Updated the code architecture research section to include optimized camera-based obstacle detection and other enhancements.
2026-08-12 Update Raspberry Pi model in README
